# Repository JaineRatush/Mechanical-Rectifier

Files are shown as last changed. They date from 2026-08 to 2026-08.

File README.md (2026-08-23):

# Mechanical Rectifier [Apr-May 2025]  
A project that converts non-uniform input to a constant rotational output. My team of 3 and I worked on in Spring 2025. 
<div align="center">
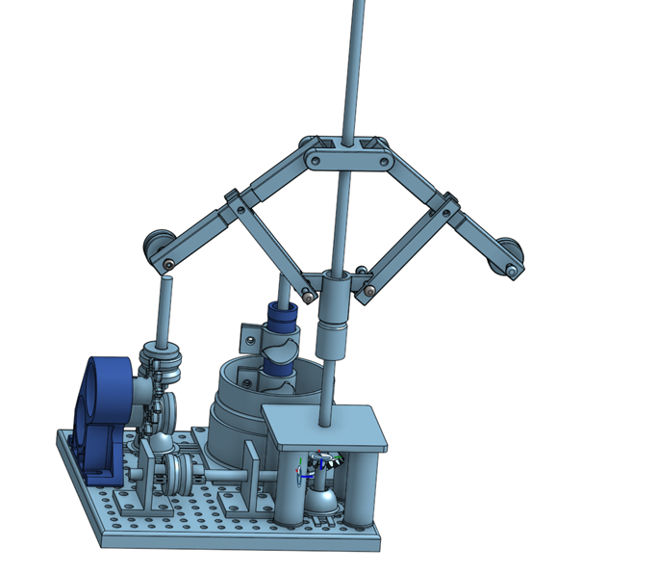
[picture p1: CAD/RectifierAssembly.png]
  
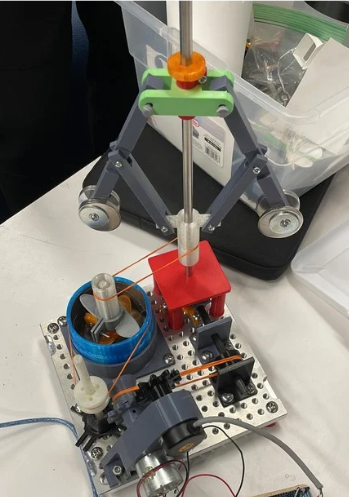
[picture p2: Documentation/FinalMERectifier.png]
  
</div> 

## Purpose & Requirements
- Prototype and design a mechanical system that can convert random sinusoidal motion to constant rotational motion.
- Connect components together using tolerances, whilst limiting the use of fasteners and eliminating the use of glue.
- The system must fit within 180cm x 180cm optical breadboard.
- The system must be able to be assembled and deconstructed within 3 minutes.
- Analyze output and create a technical report concluding the Mechanical Rectifier.

## Contributions
- Modeled the [exploded](CAD/RectifierExploded.png) and [unexploded CAD assembly](CAD/RectifierAssembly.png).
- Designed the base, cup, and base-to-cup connection of the [fluid rotation system](FluidSubsystem.png).
- Designed pulleys with connectors to gears.
- Designed the centrifugal governor legs and spline/linear bearing connector.
- Created subsystem flow charts to display each component's relations.[Pg 22-25](Documentation/MechanicalRectifier_AnalysisAssemblySection.pdf)
- Organized a bill of materials.[Pg 26](Documentation/MechanicalRectifier_AnalysisAssemblySection.pdf)  
  [Final Iteration & Results](CAD/Results.png)
 
Contributors: Hannah M., Zara B., Ryan L. , Jaine R.

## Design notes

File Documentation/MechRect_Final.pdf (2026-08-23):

### EID 103 Final Report: Mechanical Rectifier

Jaine Turban, Hannah Mandel, Zara Bhuiyan, Ryan Lee

The Cooper Union for the Advancement of Science and Art

The Albert Nerken School of Engineering

Principles of Design, Spring 2025, EID 103

Professor Giglia

5/15/2025

2

Table of Contents:

3

Project Description:

The purpose of a mechanical rectifier is to take a non-constant input and convert it into a

constant output. In this case, the input was non-constant rotary motion, where power was input as

a sinusoidal function. There were several constraints the mechanical rectifier had to follow. For

one, the assembly had to be quick to assemble. Specifically, it had to be possible to assemble the

mechanical rectifier in less than 5 minutes. In addition, the system had to have a feature to mesh

with the encoder gear, as well as measure the input and output rotational speeds. The output

rotation had to spin a disk within 25.4 mm(1 inch) and 76.2 mm(3 inches). Furthermore, the system

could not simply be compatible with one frequency: It had to work for frequencies of 1Hz, 0.5Hz,

and 0.25Hz. The system also had to take less than 10 seconds to reach a constant state. Finally, the

design of the system had to be safe: No parts could spin more than they were meant to, as that

would pose a considerable safety hazard.

4

Engineering Design Process & Iterative design

The initial objective was to research a multitude of new systems, mainly through mapping

out systems in Plectica, and to create a reliable format for the prototype. Ranging from ratchets to

rubber gears and bicycle spokes, the team’s research process develops not only on the system’s

desired dimensions, but also on what specific parts may be used for the mechanical rectifier. When

the drafting process started, multiple sketches were made as a list of potential machine concepts,

specifically narrowing on four to decide on, measuring out the main pros and cons, in terms of

efficiency and capability to manufacture and assemble.

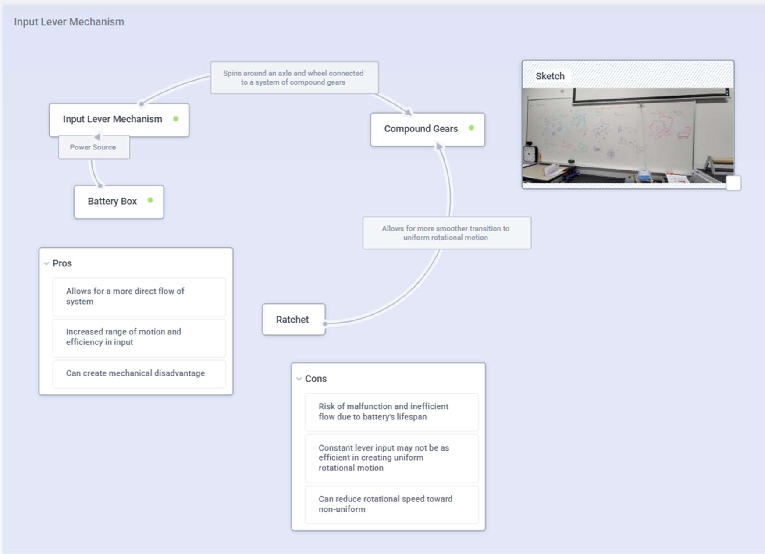
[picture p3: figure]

Figure 1: Input Lever Mechanism

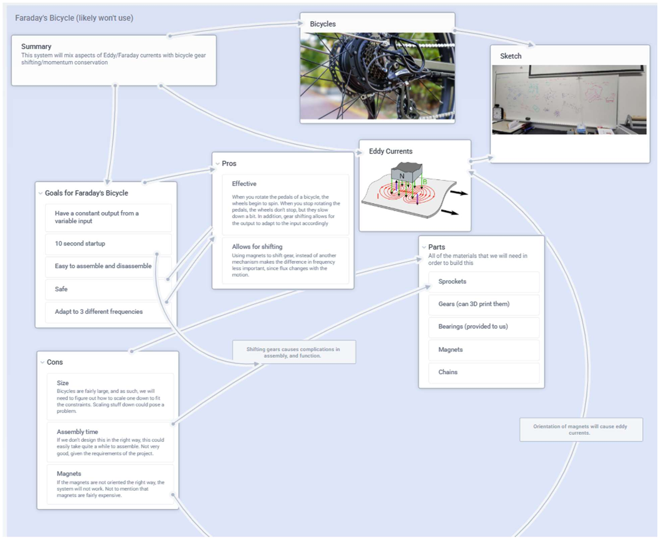
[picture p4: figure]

5

The proposal for the input lever mechanism, designed to balance out the non-constant

motion of the gears through ratchets. While this can help raise efficiency in input, alongside having

a greater mechanical disadvantage and flow of system, this can lead to risk in terms of battery,

alongside possibly even reducing the rotational speed.

Figure 2: Faraday's Bicycle

The proposal for a design utilizing Faraday’s bicycle alongside special magnets and chains

for supports, where the magnets’ orientation will bring Eddy Currents to create lesser differences

6

in frequency. While this can be easy to assemble, and adaptable to other variable rotational speeds,

the project is also time-costing, alongside having complications in assembling and functionality.

Figure 3: Hydraulic Centrifugal Governor

The proposal for the hydraulic centrifugal governor, utilizing governor circles and new

concepts of hydraulic mechanics, through its output mechanism of a fluid container, connected to

a petal gear. While its system can provide usefulness towards whole, unique machines, alongside

having simple travel within its subsystems, this inclusion of hydraulic mechanics may be

complicated, inefficient, and possibly dangerous, considering the density of common liquids, as

with water.

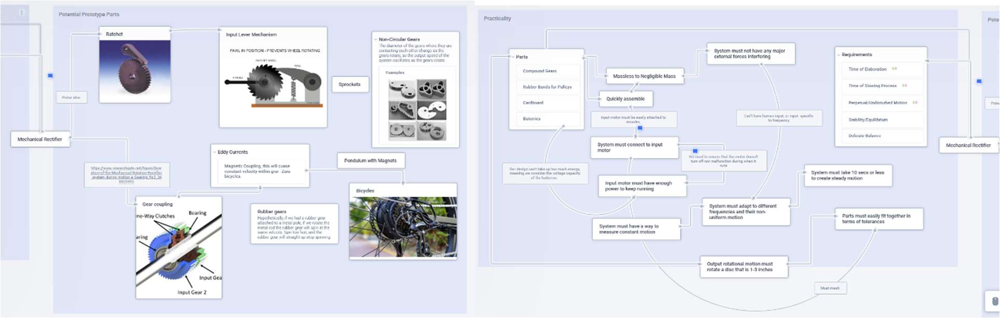
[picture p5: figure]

7

Figs 4+5: Research Plecticas

Above is the map of the entire brainstorming and research process, for both useful parts

for the prototype, the practicality of these parts, and the overall scope and requirements of the

rectifier.

Requirements | Faraday’s Bicycle | Hydraulic Centrifugal Governor | Input Lever Mechanism
Mechanical Advantage | 6 | 8 | 7
Efficiency | 7 | 8 | 4
Feasibility | 4 | 7 | 4
Total | 17 | 25 | 15

Table 1. The decision matrix for the prototype design.

8

Centrifugal Governor Supports

For the centrifugal governor to stand on the breadboard while rotating, supports must be

present to hold it in place. The support base acts as the first support, preventing motion at the

bottom of the rod containing the centrifugal governor. It is designed to fit a bearing as well as the

Long 8mm Rod, allowing rotational motion.

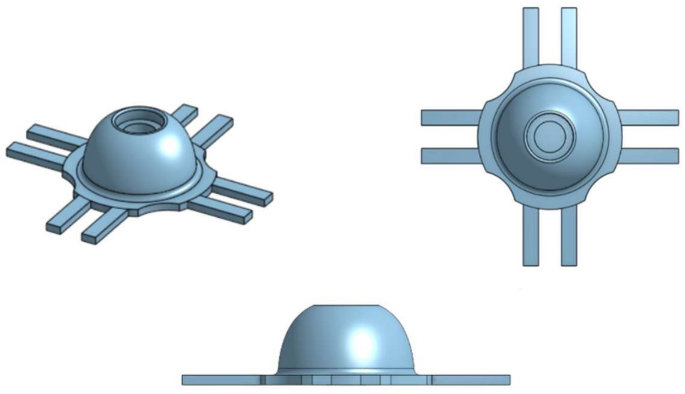
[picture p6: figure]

Figure 4: Large 8mm Rod support with top down view and side view.

After the first round of testing, the group determined that another support would be

necessary, as the centrifugal governor was unstable even with the support base. This is because the

support base only acted at the bottom of the rod: There was nothing holding the rod up closer to

the center of mass.

As such, a modular table was made to support the rod further up. It consists of 4 legs

screwed into the breadboard and a tabletop with a hole for the rod to go through. The legs are long

enough so that the table provides support above the bevel gears, allowing for the bevel gears to

rotate without interference.

9

The modular table is shown below:

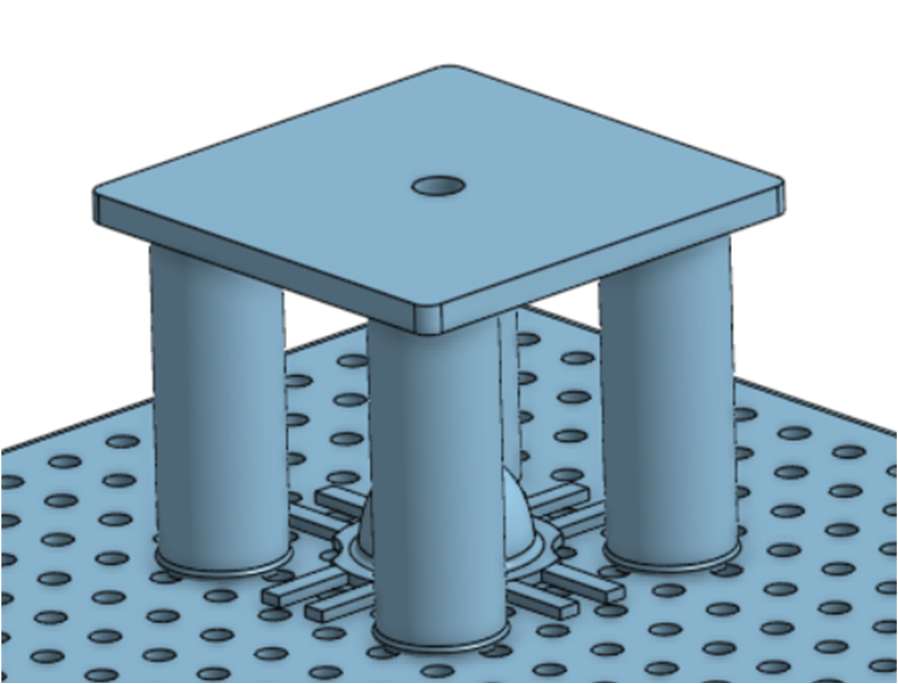
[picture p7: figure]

Fig 8. An assembly showing how the table and support base fit together on the breadboard.

Power Transfer System:

In the team’s first model, the team decided to create a pulley system. To mesh the pulley

to custom gear, the pulley had three-prongs that fit into the custom gear. While the concept

worked well, the prongs were too unstable, due to not being filleted at the surface. Additionally,

the rubber bands that converted the motion of the Three-pronged pulley to the other pulley would

constantly slip due to the smooth concavity of the pulley depicted below:

Fig 9A. The pulley that is attached to the encoder to hold the rubber band pulley system.

10

In Model 2.0, the prongs were filleted at the surface of the pulley. Additionally, the rubber band

slippage was resolved using a sharper geometry based on wells, rather than smooth concavity.

This design is shown below:

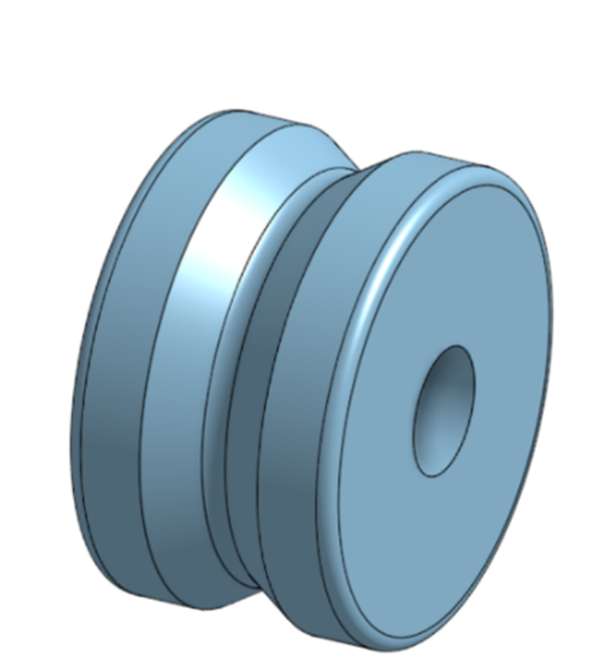
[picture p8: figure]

Fig 9B. The final design of the pulley.

Centrifugal Governor Spline:

In Model 1.0, an initial spline was to be created to allow the centrifugal governor to move

linearly up and down the Long 8mm Rod. The handles below could not be 3D printed properly

due to thin walls and the lack of precision within the 3D-Printer. The team decided that to allow

the spline to translate smoothly, the inner diameter of the spline had to coincide with the

diameter of a linear bearing(8.2mm).

11

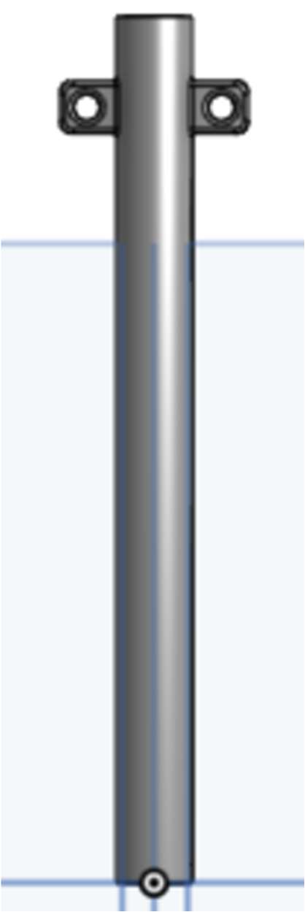
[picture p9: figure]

Fig 10. The initial design for the governor spline.

In the final model of the spline, the team decided to decrease the diameter of the spline and

use 3D printer’s mid-tolerancing instead of using a linear bearing. This choice was made as the

weight of the linear bearing impeded the centrifugal effect of the weights attached to the centrifugal

governor. Additionally, a crevice was added so a rubber bands would connect firmly to the spline,

allowing transfer of rotation to the next subsystem.

12

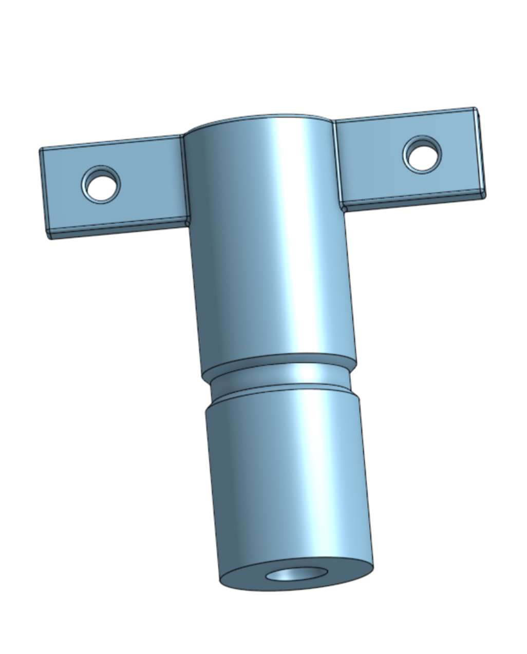
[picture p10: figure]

Fig 11. The final design for the centrifugal governor spline.

Bevel Gears:

In Model 2.0, the team would, at first, utilize bevel gears attached to two rods, one

horizontally and vertically aligned, allowed to rotate with a clamp. However, due to size

difficulties, rather it being too small for the rod to have a friction fit, the team has decided to

remove the clamp altogether, instead focusing on only the poles for supports.

13

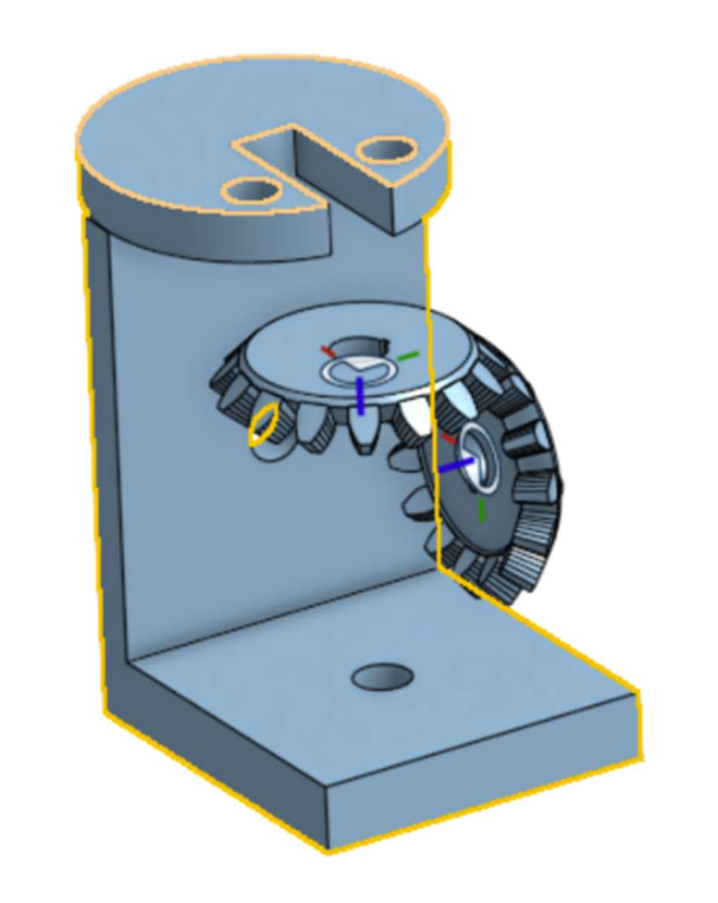
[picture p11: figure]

Fig 12. The original bevel gear design.

Cup, Table + Output Gear:

14

In Model 1.0, it was initially planned to create a large cup filled with water and a gear

strongly attached to the bottom through a makeshift hole. However, due to no agreement in

dimension between the two, alongside initial confusion upon workspace units, printing it would

lead to incompatible parts that would cover the breadboard’s majority. Therefore, the group

decided to create a flat platform for the cup.

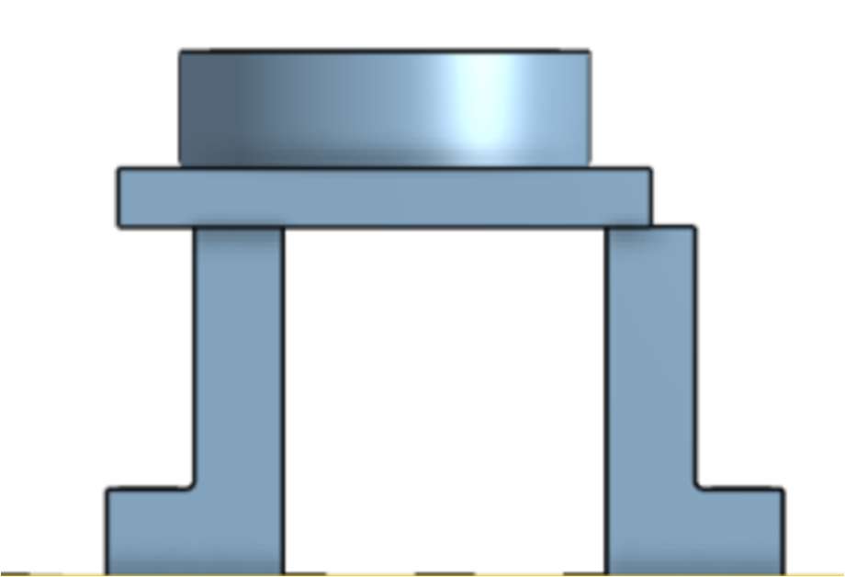
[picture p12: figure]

Fig 13. An assembly showing the first version of the cup base.

After the group revamped the entire design of the mechanical rectifier, it was decided that

the cup base did not need to be elevated, since the final output would be located next to the cup

rather than under the cup. Hence, the cup base would be screwed directly onto the breadboard.

15

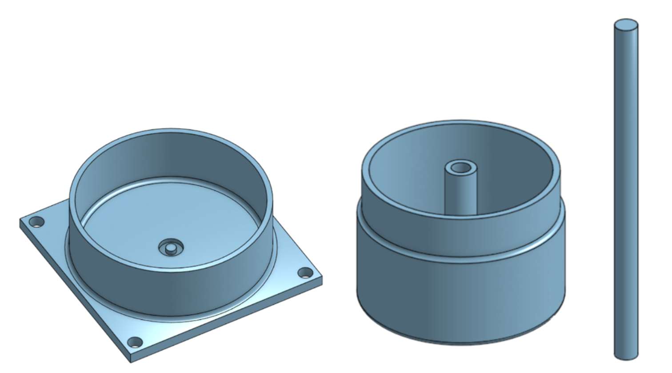
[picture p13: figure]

Fig 14. The final versions of the cup base, cup, and the rod for the cup.

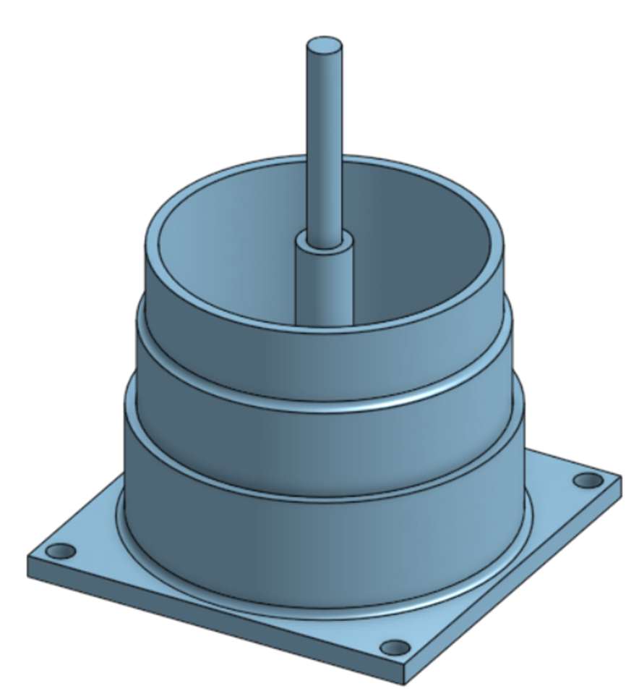
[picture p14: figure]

Fig 15. An assembly showing how the base-cup-rod system fits together.

16

Propeller Spline:

In the first design for the propeller spline, the propeller petals were directly modelled

onto the spline. Due to 3D printing limitations, only one layer of petals could be on this spline.

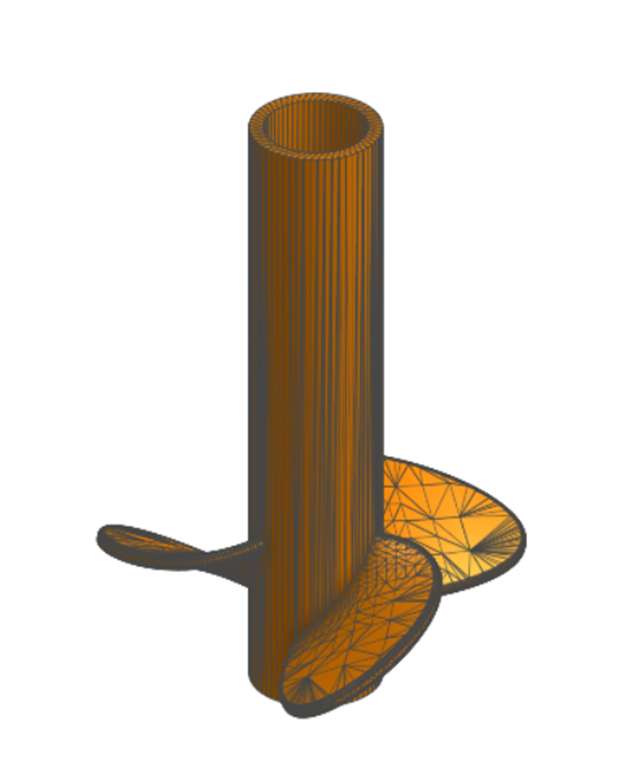
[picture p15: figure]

Fig 16. The initial design for the petal spline.

After deliberation, however, the group determined that the spline needed at least 2 layers

of petals on the spline. This is because the design operates on the difference in the amount of petals

submerged in the cup when the centrifugal governor arms are at different heights: When the arms

are higher, less of the petals will be submerged, and when the arms are lower more petals will be

submerged. At any given time, petals must be submerged in the water to ensure cup rotation.

To combat this issue, the propeller spline is broken up into 2 components: The spline itself,

and a clamp containing petals. The spline is designed to be long enough to hold multiple petal

clamps, allowing for multiple layers of petals. In addition, near the top of the spline there is an

indent that allows the rubber band to stay steady.

17

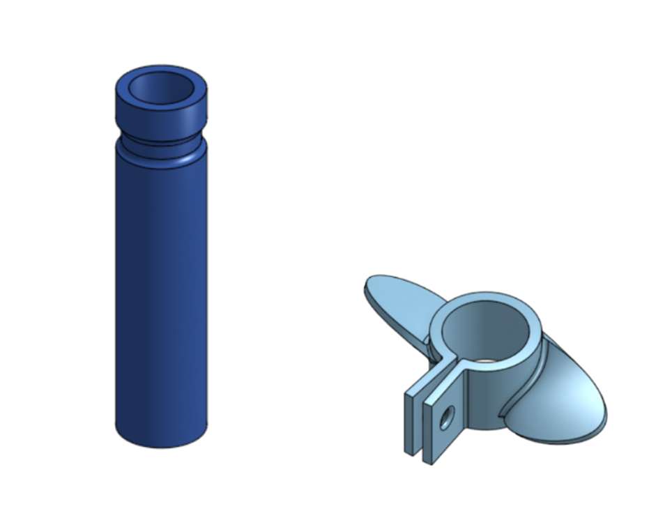
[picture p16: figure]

Fig 17. The final designs for the Large Spline and petal clamp

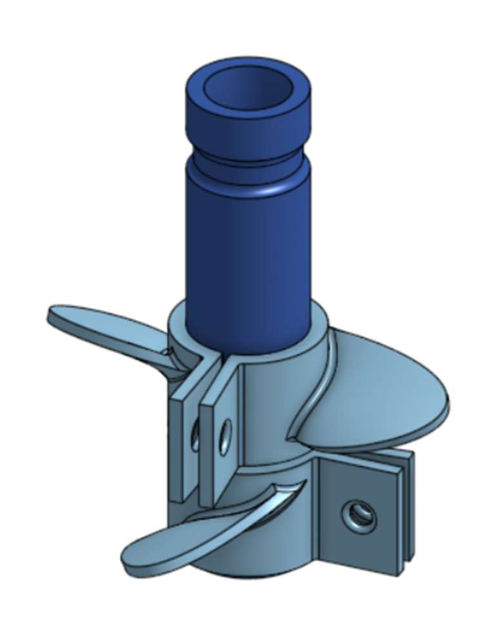
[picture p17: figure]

Fig 18. An assembly showing how the Large spline shaft and clamp fit together. There are

two layers of metals instead of one layer like in the original design.

18

The iterations above resulted from the following:

In the middle of the project the group experienced a large problem. No progress was being

made to create anything physical. Many designs and cads were created but issues of dimensioning

and how parts would fit together arose and the group was not able to resolve all of these issues in

order to print out the project and test it. Since they were unable to test if they did not know how if

the project was going to work and what big changes would need to be made. They decided to take

a moment to rethink the project. They realized the problem was that they were trying to stack all

the subsystems on top of each other and this was causing issues with fitting and supporting the

system. They decided to get a working centrifugal governor to print so they could test it and then

figure out what to do next. They re-examined all their designs and created a new design that would

separate all their subsystems onto the breadboard. This new design effectively resolved their issues

with supporting the system and to better visualize the power transfer. Furthermore, their completed

centrifugal governor allowed them to design the other subsystems to fit around it.

19

The images below are sketches of the team’s final design, after the team brainstormed

about the above iterations and redesigning the system such that complicated structures did not

have to be involved.

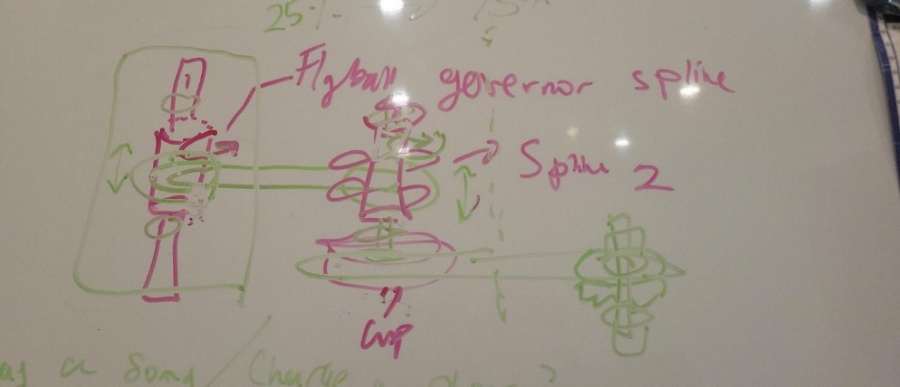
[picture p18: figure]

Figs 19 + 20. This image shows one of the many redesigns of the prototype, involving bevel

gears to rotate the gear’s direction and fluid forces to stabilize the system, emphasizing on the

cup and propeller’s significance.

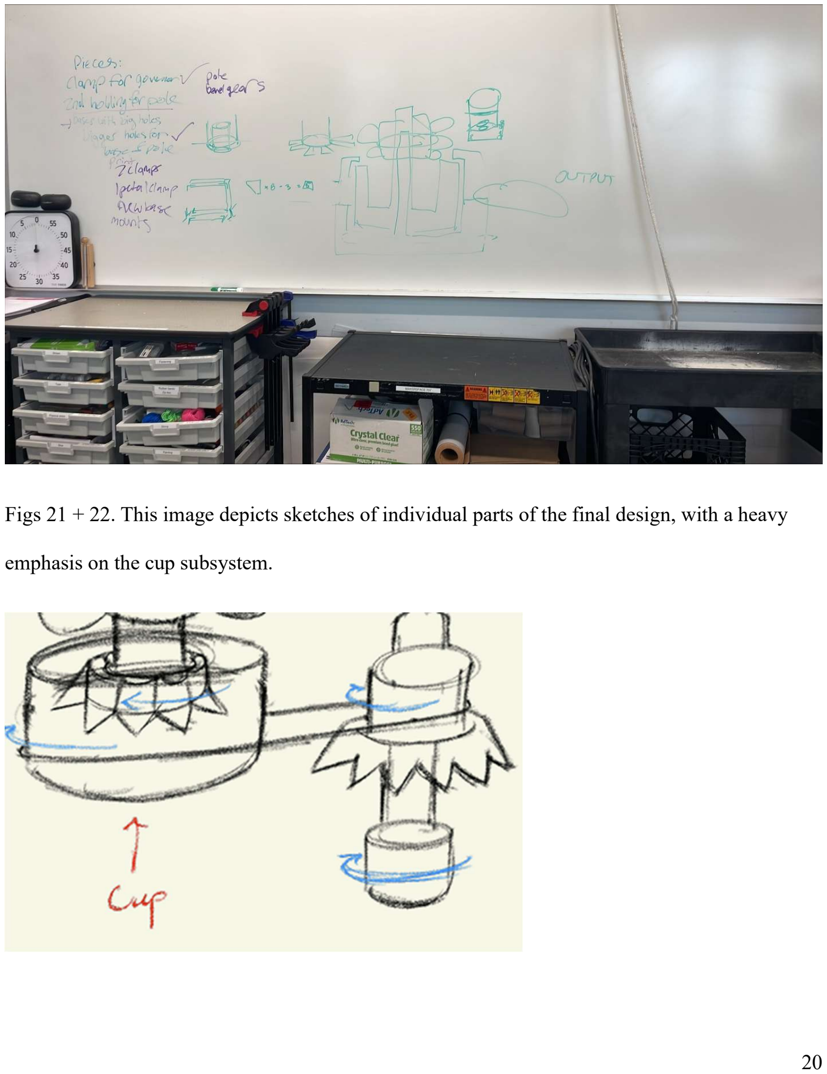
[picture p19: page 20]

20

Figs 21 + 22. This image depicts sketches of individual parts of the final design, with a heavy

emphasis on the cup subsystem.

21

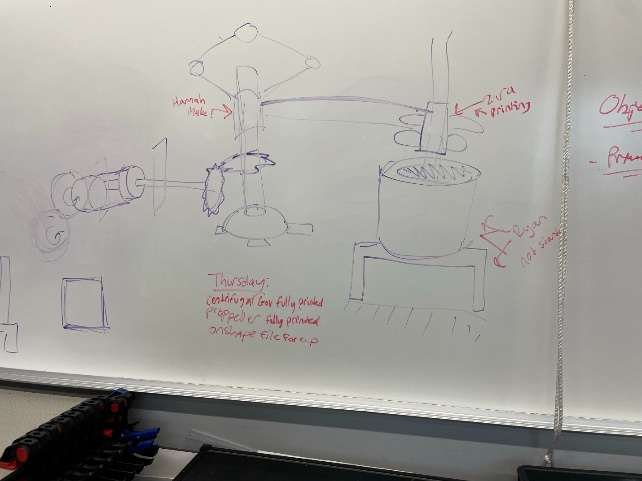
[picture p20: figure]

Figs 23 + 24 + 25. These are closer views of the sketch of the final design. This view

emphasizes the connection between the cup subsystem and the output.

22

### Analysis of the design:

Power Transfer:

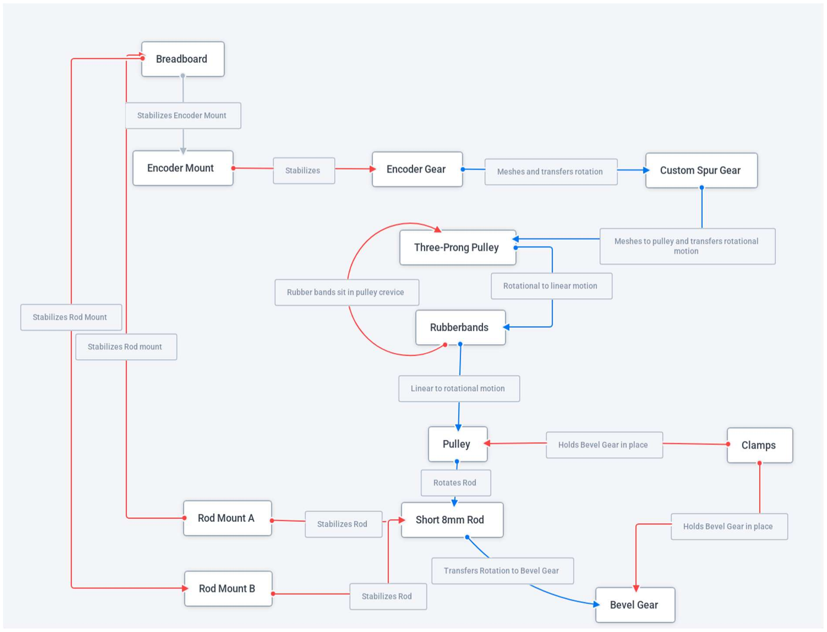
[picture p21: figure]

To transfer the non-uniform motion to the system, the team decided on a pulley system. As

the Encoder gear rotates, the three-pronged pulley rotates. This motion is transferred from the

three-pronged pulley to a second pulley, which is attached to a Short Rod 8mm in diameter.

Attached to the end of the rod is a bevel gear. As the rod rotates, the bevel gear rotates at the same

rate, transferring motion by 90 degrees to the next subsystem.

23

Centrifugal Governor:

The Centrifugal Governor arms hold weights and are attached to the Large 8mm Rod

through the collar. The Large 8mm Rod rotates due to a bevel gear meshing to the previous

subsystem. As the Large 8mm Rod rotates at a faster rate, the centrifugal force(force that causes

something to spin in a circle) produced due to the mass of the weights, causes the arms to rise.

24

Since the motion from the encoder is non-uniform, the arms of the centrifugal governor effectively

buff the change in rotational velocity. This vertical movement is captured through the legs and

Small Spline of the centrifugal governor. Since the legs are connected to both the arms and the

Small Spline, the vertical movement of the arms is transferred to the spline. As a result of this, the

spline has linear and rotational motion along the Long 8mm Rod that it can transfer to the Fluid

subsystem through rubber bands.

Fluid Subsystem:

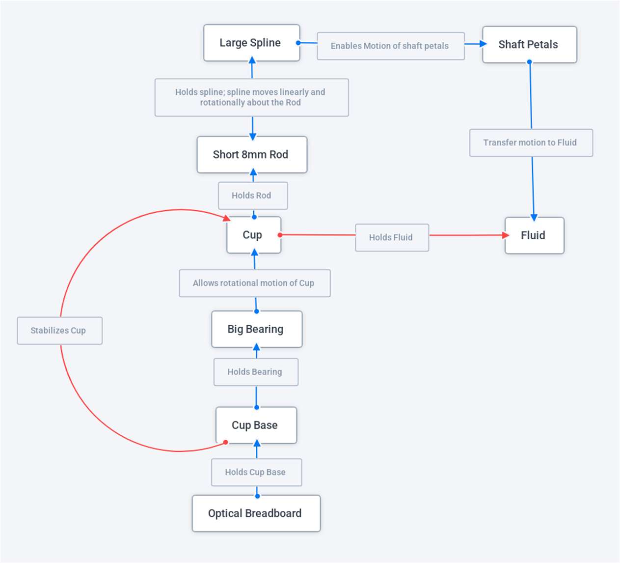
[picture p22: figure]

Attached to the cup through a Short 8mm Rod is a Large Spline. Due to the spline in the

previous subsystem, the Large Spline gains linear and rotational motion. Attached to the Large

Spline are Petals which follow the same motion. The Petals convert rotational motion to the fluid.

The momentum of the rotating fluid causes the Cup to rotate. Referring to previous subsystem

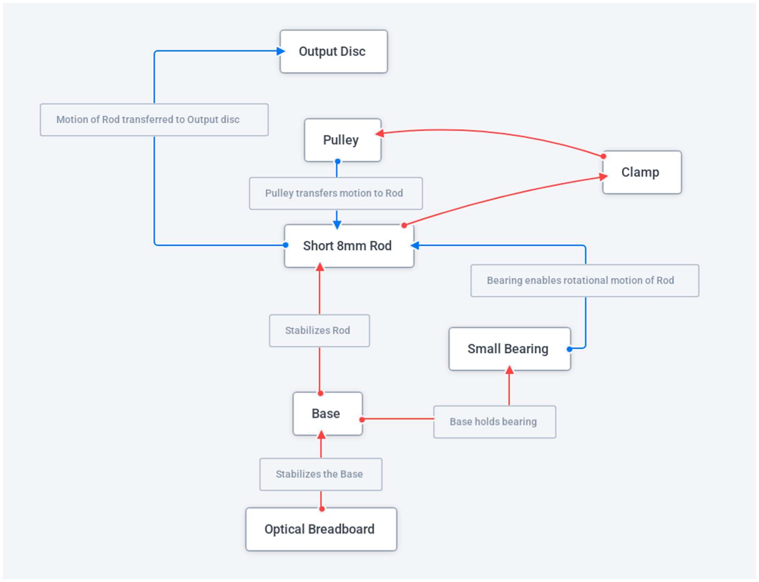
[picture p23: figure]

25

analysis, as the non-uniform motion changes, the number of petals in the fluid changes.

Consequently, the rotational speed of the fluid and the cup change to account for the non-uniform

motion. Connected to the Cup are rubber bands, which transfer the rotational motion of the Cup to

the next subsystem.

Output:

To transfer the rotational motion of the previous subsystem to the Output, rubberbands are

placed on a pulley, connecting the Cup of the Fluid Subsystem to this subsystem. The pulley is

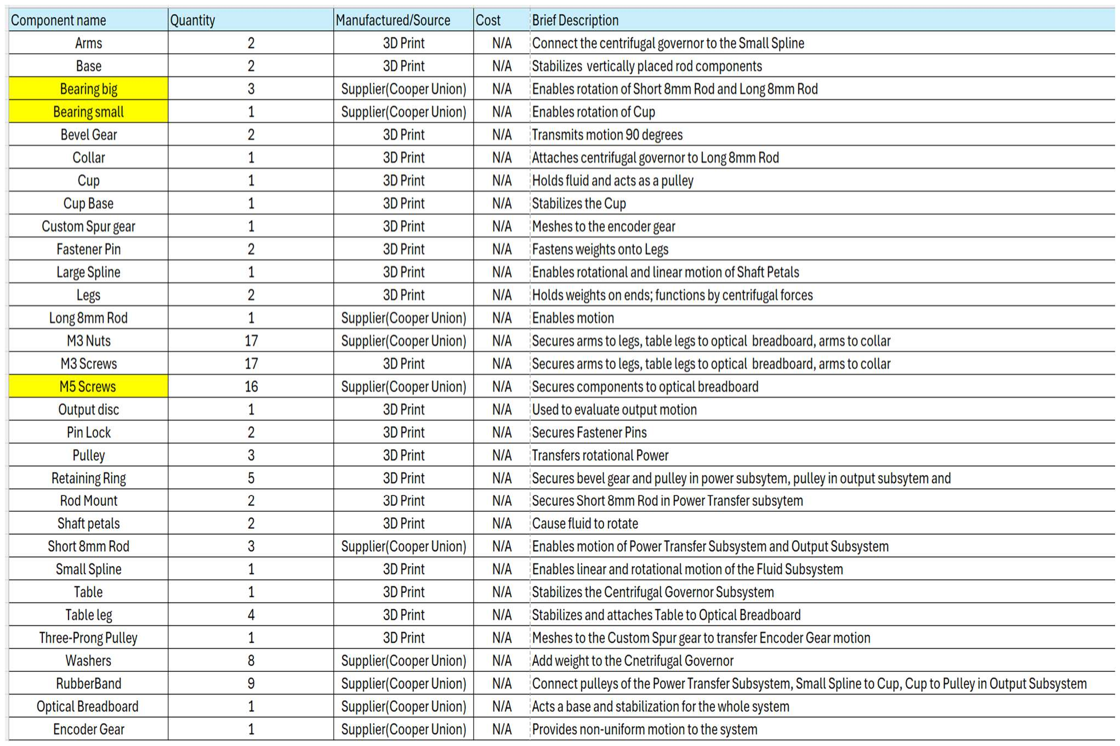
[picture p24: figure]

26

connected to a Short 8mm Rod to enable rotation. An output disc is attached to this rod to observe

the final output of the Mechanical Rectifier.

Bill of Materials:

27

Exploded view of assembly:

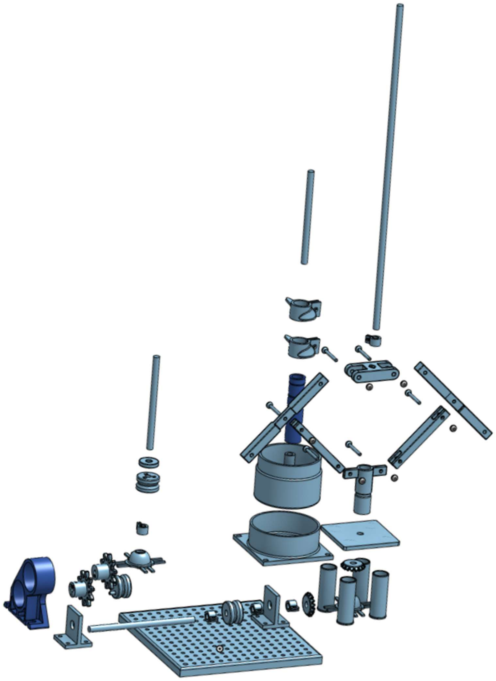
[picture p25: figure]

28

Normal View of Assembly:

29

### Outcome Analysis:

Voltage | Encoder angular velocity(radians/second) | Rectifier angular velocity(degrees/second)

6V

7.5V

9V

12V

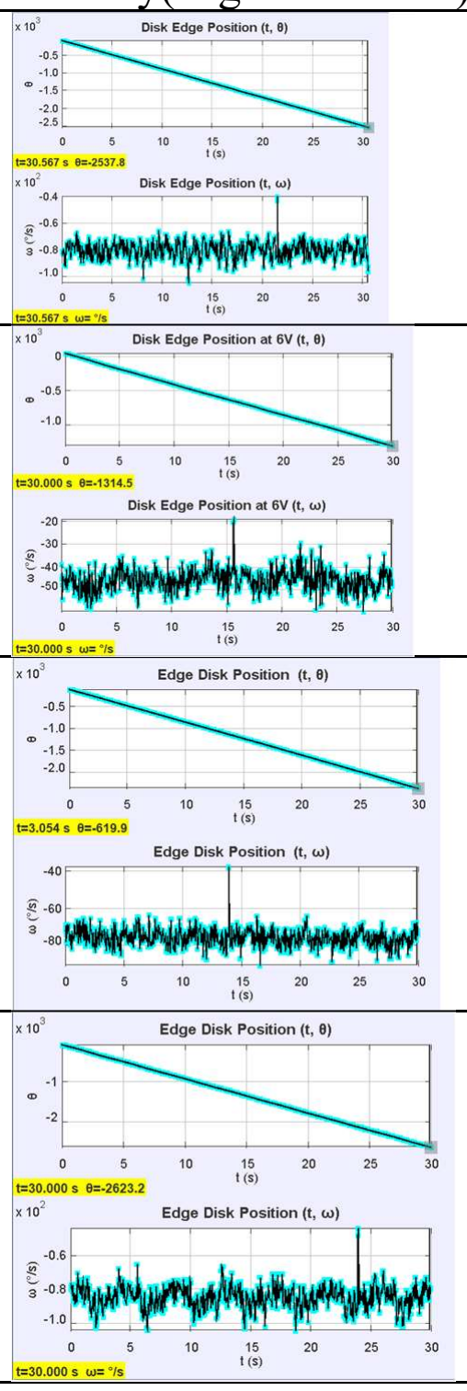
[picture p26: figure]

Table 1: Graphs of Angular velocity vs time for non rectified and Mechanical rectified system for

the four tested voltages and Graphs of the Mechanical Rectifier system of angular position vs time

for the four different tested Voltages.

Table 1 displays the angular displacement and angular velocity of the encoder gear and the

disk atop the centrifugal governor. The angular displacement and velocity of both components

were measured at four different voltages to test the effectiveness of the mechanical rectifier.

30

The graphs in Table 1 show the angular velocity oscillating with large amplitudes according

to the inputs of the encoder gear. The graphs of the angular velocity of the mechanical rectifier at

these same voltages have a much smaller amplitude during the oscillation. This shows that the

angular velocity of the output is extremely consistent compared to the input power. Furthermore,

the graph of the rotation angle against time is linear, showing the consistency in movement of the

output. Since the derivative of the rotation angle with respect to time is the angular velocity and

the graphed angle is linear, the angular velocity would be constant. This is not the case as shown

in the angular velocity graphs but it is very close to constant. The mechanical rectifier this group

created severely dampened the amplitude of the oscillation, making the output essentially constant

with negligible interference. This was shown by comparing the graphs of the angular velocity of

the non-rectified system with the graphs of angular velocity of the rectified system. The large

oscillations in the graphs of the former are severely dampened in the graphs of the latter. The

linearity of the angle and the close-to-constant angular velocity proved that this system which used

a centrifugal governor, a rubber band pulley system, and slippage between each subsystem was an

effective mechanical rectifier.

dB = 20 ∗ log(

A
A

)

31

Voltage | Amplitude Without Rectifier(degrees/second) | Amplitude of Rectifier(degrees/second) | Decibel Scale
6V | 171 | 16.9 | -20.1
7.5V | 237 | 25.9 | -19.2
9V | 259 | 17.7 | -23.3
12V | 337 | 31.6 | -20.6

Table 2: Decibel scale calculations with amplitude.

The angular velocity of the non rectified system, regardless of voltage, oscillates with a

much higher amplitude than the angular velocity of the rectified system. This is due to the level of

dampening provided by the mechanical rectifier, which ranged from -23.3 dB to -19.2 dB. Even if

the angular velocity vs. time graph for the rectified system still oscillates, its amplitude is so much

lower than the unrectified system that it is relatively fixed compared to the unrectified system.

### Future work & Conclusion:

If the group were to repeat this project in the future, several changes would have to be made to

ensure a more functional result. For one, on a more logistical scale, the original design for the

mechanical rectifier proved to be too difficult to execute, however the design was changed very

late into the production timeline of the project. Thankfully, the original design and final design

shared similar components, and as such not much work was scrapped. If this project were done

again, the design would need to be fully formulated well before the production of parts to maximize

efficiency.

32

Through the problems experienced during this project, the group learned valuable lessons in

communication and working in a team. Redoing this project with that experience would cause

much smoother and more efficient work. Furthermore, early failures with dimensioning would be

solved with better understanding of what comes out of a 3D printer that was gained from failed

prints. With more time, a more in depth analysis of the system and its flaws would be achieved

and the group would work to improve these flaws. The group has issues finding the best way to

transfer power. They decided on a rubber band pulley system due to the ease of use and the strength

of the friction between the rubber band and the pulley. The belt was found to have a worse

connection to the pulley and was difficult to assemble. While the rubber band was chosen, it wasn’t

the perfect choice. There were issues transferring power because the rubber bands have lots of

tension in them and stretch. This caused imperfect power transfer because some power was lost in

the rubber band. Furthermore, the rubber band tended to get caught and stop movement all together.

In future iterations of this design a better method of power transfer would be found and tested.

Another issue was the centrifugal governor wasn’t perfectly connected to the encoder. Since the

parts of the centrifugal governor that were connected to the pole were not friction fit, there was an

imperfect power transfer between the encoder and the output. The group had concerns that this

would negatively affect the final results. While testing, the group realized that this imperfect

transfer of power was actually beneficial and the slippage between the centrifugal governor and

the rest of the system was taking away energy that would have caused a larger oscillation in the

output.

33

Through analysis of the oscillation of the output angular velocity, the group realized the output

velocity was very close to constant and determined their mechanical rectifier a success. While they

came across many difficulties that they will work to fix such as communication problems and

failure in dimensioning and fitting parts and subsystems together, the group learned valuable skills

in problem solving, the design process, power transfer, and teamwork.

34

### Acknowledgements:

We would like to acknowledge Professor Micheal Giglia and Mr. Douglass Thornhill for

their guidance throughout the project, as well as for posing this challenge in the first place.

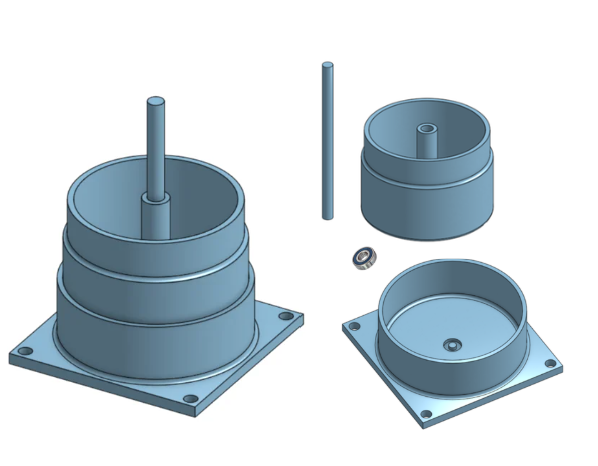
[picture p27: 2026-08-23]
CAD/FluidSubsystem.png

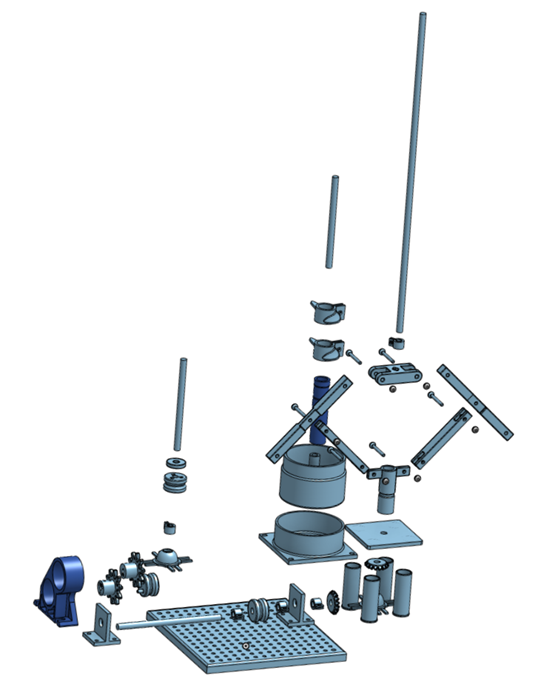
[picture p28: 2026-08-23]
CAD/RectifierExploded.png

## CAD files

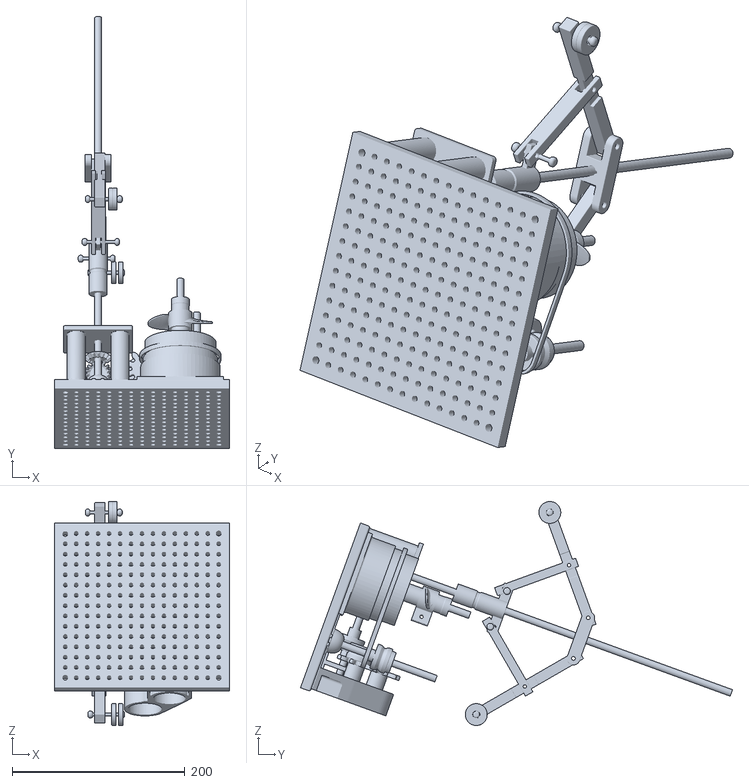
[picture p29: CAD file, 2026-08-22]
CAD/Mech Rectifier Assembly.stl
203.2 x 500.7 x 259.5

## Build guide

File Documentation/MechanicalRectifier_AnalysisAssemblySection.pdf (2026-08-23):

22

### Analysis of the design:

Power Transfer:


To transfer the non-uniform motion to the system, the team decided on a pulley system. As

the Encoder gear rotates, the three-pronged pulley rotates. This motion is transferred from the

three-pronged pulley to a second pulley, which is attached to a Short Rod 8mm in diameter.

Attached to the end of the rod is a bevel gear. As the rod rotates, the bevel gear rotates at the same

rate, transferring motion by 90 degrees to the next subsystem.

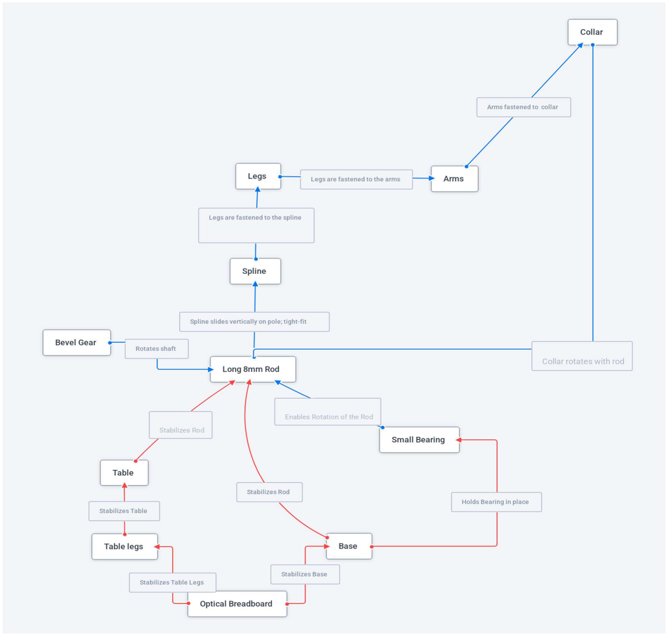
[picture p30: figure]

23

Centrifugal Governor:

The Centrifugal Governor arms hold weights and are attached to the Large 8mm Rod

through the collar. The Large 8mm Rod rotates due to a bevel gear meshing to the previous

subsystem. As the Large 8mm Rod rotates at a faster rate, the centrifugal force(force that causes

something to spin in a circle) produced due to the mass of the weights, causes the arms to rise.

24

Since the motion from the encoder is non-uniform, the arms of the centrifugal governor effectively

buff the change in rotational velocity. This vertical movement is captured through the legs and

Small Spline of the centrifugal governor. Since the legs are connected to both the arms and the

Small Spline, the vertical movement of the arms is transferred to the spline. As a result of this, the

spline has linear and rotational motion along the Long 8mm Rod that it can transfer to the Fluid

subsystem through rubber bands.

Fluid Subsystem:


Attached to the cup through a Short 8mm Rod is a Large Spline. Due to the spline in the

previous subsystem, the Large Spline gains linear and rotational motion. Attached to the Large

Spline are Petals which follow the same motion. The Petals convert rotational motion to the fluid.

The momentum of the rotating fluid causes the Cup to rotate. Referring to previous subsystem


25

analysis, as the non-uniform motion changes, the number of petals in the fluid changes.

Consequently, the rotational speed of the fluid and the cup change to account for the non-uniform

motion. Connected to the Cup are rubber bands, which transfer the rotational motion of the Cup to

the next subsystem.

Output:

To transfer the rotational motion of the previous subsystem to the Output, rubberbands are

placed on a pulley, connecting the Cup of the Fluid Subsystem to this subsystem. The pulley is


26

connected to a Short 8mm Rod to enable rotation. An output disc is attached to this rod to observe

the final output of the Mechanical Rectifier.

Bill of Materials:

27

Exploded view of assembly:


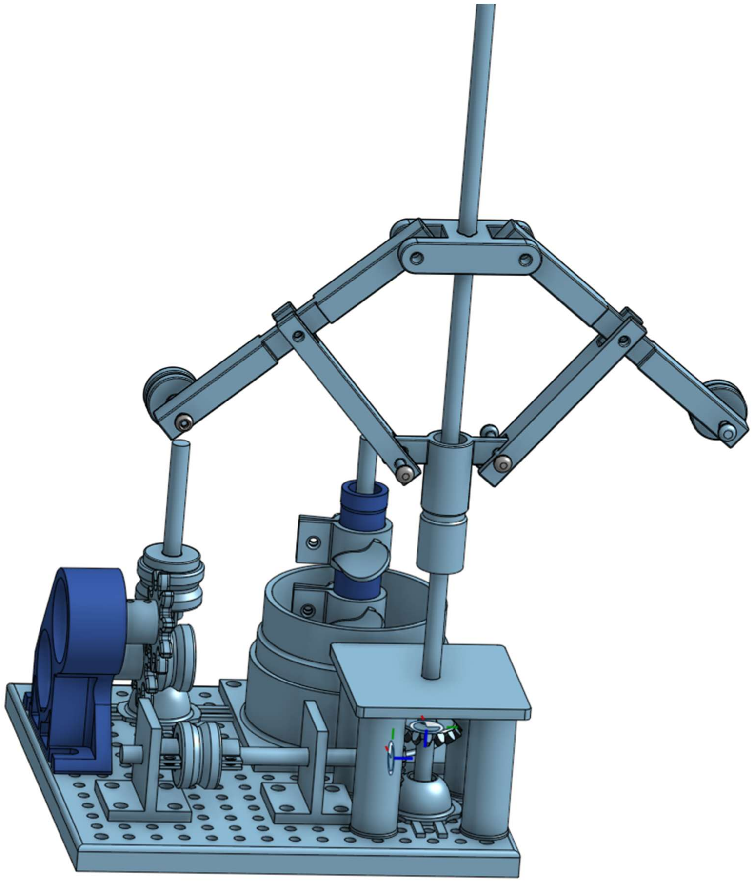
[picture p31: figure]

28

Normal View of Assembly:

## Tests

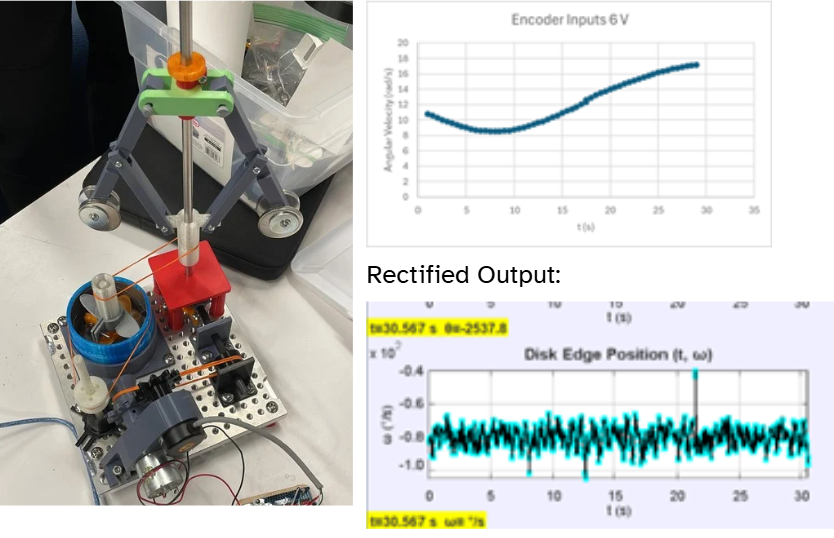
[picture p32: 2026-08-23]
CAD/Results.png
